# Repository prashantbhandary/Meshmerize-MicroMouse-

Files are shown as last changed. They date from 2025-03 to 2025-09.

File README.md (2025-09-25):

# 🤖 Meshmerize MicroMouse Project





> **A comprehensive autonomous line-following and maze-solving robot project featuring multiple hardware iterations, advanced algorithms, and professional PCB designs.**

## 🏆 Competition Achievements

Our MicroMouse has proven its excellence in prestigious robotics competitions:

- 🥇 **1st Place** - Locus, Pulchowk Campus  
- 🥈 **2nd Place** - Delta 5.0, Dharan IOE  
- 🏅 **5th Place** - Techfest, IIT Bombay 2024

<div align="center">

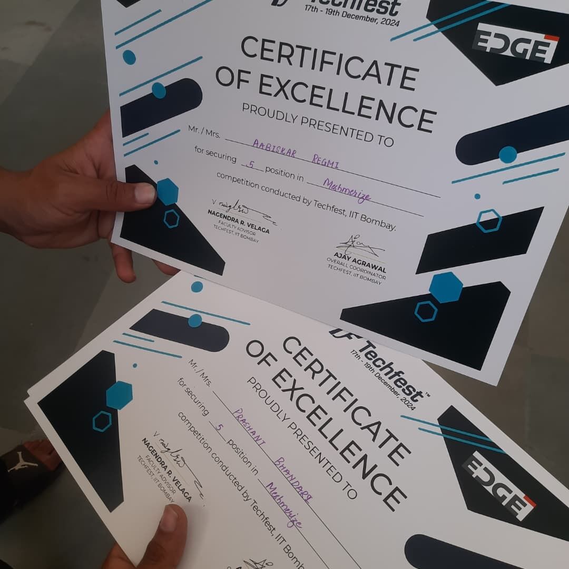
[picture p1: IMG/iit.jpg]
IIT Bombay Certificate

*Certificate of Achievement from IIT Bombay Techfest 2024*

</div>

---

## 📋 Table of Contents

- [🎯 Project Overview](#-project-overview)
- [✨ Key Features](#-key-features)
- [🔧 Hardware Versions](#-hardware-versions)
- [💻 Software Architecture](#-software-architecture)
- [🚀 Getting Started](#-getting-started)
- [📁 Repository Structure](#-repository-structure)
- [🛠️ Installation & Setup](#️-installation--setup)
- [🎮 Usage Instructions](#-usage-instructions)
- [🧠 Algorithms & Control Systems](#-algorithms--control-systems)
- [📷 Project Gallery](#-project-gallery)
- [🤝 Contributing](#-contributing)
- [📄 License](#-license)

---

## 🎯 Project Overview

The **Meshmerize MicroMouse** is an autonomous robot designed to navigate line-following courses and solve complex mazes. This project showcases the evolution of robotics engineering through multiple hardware iterations, from Arduino Nano-based prototypes to advanced ESP32-powered systems.

### What Makes This Project Special?

- **Multiple Hardware Generations**: Evolution from v1.0 to v3.1 with continuous improvements
- **Dual Platform Support**: Both Arduino Nano and ESP32 implementations
- **Professional PCB Design**: Custom-designed circuit boards using KiCad
- **Advanced Algorithms**: LSRB maze-solving with optimized PID control
- **Competition-Tested**: Proven performance in national and international competitions

---

## ✨ Key Features

### 🎯 **Navigation Capabilities**
- **Line Following**: Precise black/white line detection and following
- **Maze Solving**: Autonomous exploration and shortest path execution
- **Multi-Surface Support**: Adaptable to different track conditions

### ⚡ **Performance Optimization**
- **PID Control System**: Smooth and accurate movement control
- **Speed Management**: Adaptive speed control for different track sections
- **Sensor Calibration**: Advanced sensor tuning for reliable detection

### 🔧 **Hardware Excellence**
- **Custom PCB Design**: Professional circuit board layouts
- **Modular Architecture**: Easy maintenance and upgrades
- **Power Management**: Efficient voltage regulation for all components

---

## 🔧 Hardware Versions

<details>
<summary><strong>Arduino Nano Series</strong></summary>

### Version 1.0 - Prototype
- **Microcontroller**: Arduino Nano
- **Motor Driver**: L293D
- **Sensors**: QTR-8A analog sensor array
- **Status**: Initial prototype and testing phase

### Version 2.0 - Enhanced Performance
- **Microcontroller**: Arduino Nano (optimized)
- **Motor Driver**: SparkFun TB6612FNG
- **Sensors**: 8-channel QTR sensor array
- **Improvements**: Better motor control, enhanced PID tuning
- **PCB**: Custom-designed v2.0 PCB

### Version 3.0/3.1 - Professional Grade
- **Microcontroller**: Arduino Nano
- **Features**: Professional PCB design with improved layout
- **Status**: Competition-ready version

</details>

<details>
<summary><strong>ESP32 Series</strong></summary>

### ESP32 Version 1.0
- **Microcontroller**: ESP32 DevKit
- **Development**: PlatformIO-based development
- **Features**: 
  - Wireless capabilities
  - Higher processing power
  - Advanced sensor integration
- **PCB**: Custom ESP32-based PCB design

</details>

---

## 💻 Software Architecture

### Programming Platforms
- **Arduino IDE**: Traditional Arduino Nano development
- **PlatformIO**: Advanced ESP32 development with better library management

### Key Libraries
```cpp
#include <SparkFun_TB6612.h>  // Motor control library
#include <QTRSensors.h>       // Sensor array library
```

### Algorithm Implementation
- **LSRB Algorithm**: Left-Straight-Right-Back priority maze solving
- **PID Control**: Proportional-Integral-Derivative control for smooth movement
- **Path Optimization**: Shortest path calculation and execution

---

## 🚀 Getting Started

### Prerequisites
- Arduino IDE or PlatformIO
- USB cable for programming
- Basic electronics knowledge
- Robotics track or maze for testing

### Quick Setup
1. **Clone the repository**
   ```bash
   git clone https://github.com/prashantbhandary/Meshmerize-MicroMouse-.git
   cd Meshmerize-MicroMouse-
   ```

2. **Choose your platform**
   - For Arduino Nano: Navigate to `ArduinoNano/` folder
   - For ESP32: Navigate to `Esp32/` folder

3. **Select the appropriate version**
   - Pick the version that matches your hardware setup
   - Latest versions recommended for best performance

---

## 📁 Repository Structure

```
📦 Meshmerize-MicroMouse-
├── 🔧 ArduinoNano/
│   ├── 🧪 arduno_nano_v1_TestingCode/
│   │   ├── arduino_sensor_test2.0/
│   │   ├── black_line_maze_2.0/
│   │   ├── motor-testing/
│   │   └── night_nano/
│   ├── 📋 micro_mouse_v1-files/
│   │   ├── codes/ (Line follower, maze solving, testing)
│   │   └── design/ (3D models, PCB files)
│   ├── 🚀 micro_mouse_v2-files/
│   │   ├── BlackLineMazeFinal_v2-Code/
│   │   ├── LineFollowerPid_v2-Code/
│   │   ├── WhiteLineMazeFinal_v2-Code/
│   │   └── micro_mouse_v2-pcb/
│   └── 🏆 micro_mouse_v3_files/
│       ├── micro_mouse_prashant/
│       ├── micro_mouse_v3.0-PCB/
│       └── micro_mouse_v3.1-PCB/
├── 📡 Esp32/
│   ├── LineFolloweEsp32_v1_code/
│   ├── micromouseEsp32_v1_PCB/
│   └── testing_esp32_v1_code/
├── 📸 IMG/
│   ├── Competition videos and images
│   └── Robot demonstration media
└── 📖 README.md
```

---

## 🛠️ Installation & Setup

### For Arduino Nano Versions

1. **Install Required Libraries**
   ```
   - SparkFun TB6612 Motor Driver Library
   - QTRSensors Library
   ```

2. **Hardware Setup**
   - Connect QTR sensors to analog pins A0-A7
   - Wire motor drivers according to pin definitions
   - Connect control switches and LED indicators

3. **Upload Code**
   - Open the desired version in Arduino IDE
   - Select Arduino Nano board
   - Upload the code

### For ESP32 Version

1. **PlatformIO Setup**
   ```bash
   cd Esp32/LineFolloweEsp32_v1_code/Micromouse/
   pio run --target upload
   ```

2. **Hardware Configuration**
   - Follow ESP32 pin definitions in the code
   - Ensure proper power supply (3.3V/5V compatibility)

---

## 🎮 Usage Instructions

### Initial Setup
1. **Calibration Phase**
   - Press switch 1 to start sensor calibration
   - Move the robot over the line during calibration
   - LED indicator confirms successful calibration

2. **Mode Selection**
   - **Switch 2**: Left-hand rule (LHS) priority
   - **Switch 3**: Right-hand rule (RHS) priority

3. **Start Operation**
   - Press switch 1 again to begin line following/maze solving
   - Robot will autonomously navigate the course

### Operating Modes

#### Line Following Mode
- Robot follows black line on white surface (or vice versa)
- PID control ensures smooth tracking
- Adaptive speed control for optimal performance

#### Maze Solving Mode
- **Exploration Phase**: Robot maps the entire maze
- **Optimization Phase**: Calculates shortest path
- **Execution Phase**: Runs the optimized route

---

## 🧠 Algorithms & Control Systems

### LSRB Algorithm (Left-Straight-Right-Back)
```cpp
// Priority decision making
if (left_path_available) {
    turn_left();
} else if (straight_path_available) {
    move_forward();
} else if (right_path_available) {
    turn_right();
} else {
    turn_back(); // Dead end
}
```

### PID Control System
```cpp
// PID calculation for smooth movement
error = sensor_position - desired_position;
derivative = error - lastError;
correction = (kp * error) + (kd * derivative);
motor_speed_adjustment = base_speed ± correction;
```

### Key Parameters
- **Base Speed**: 130-255 (adjustable per version)
- **Kp (Proportional)**: 0.05-0.151 (tuned per hardware)
- **Kd (Derivative)**: 0.1-0.8 (optimized for stability)

---

## 📷 Project Gallery

<div align="center">

### 🤖 Robot Images
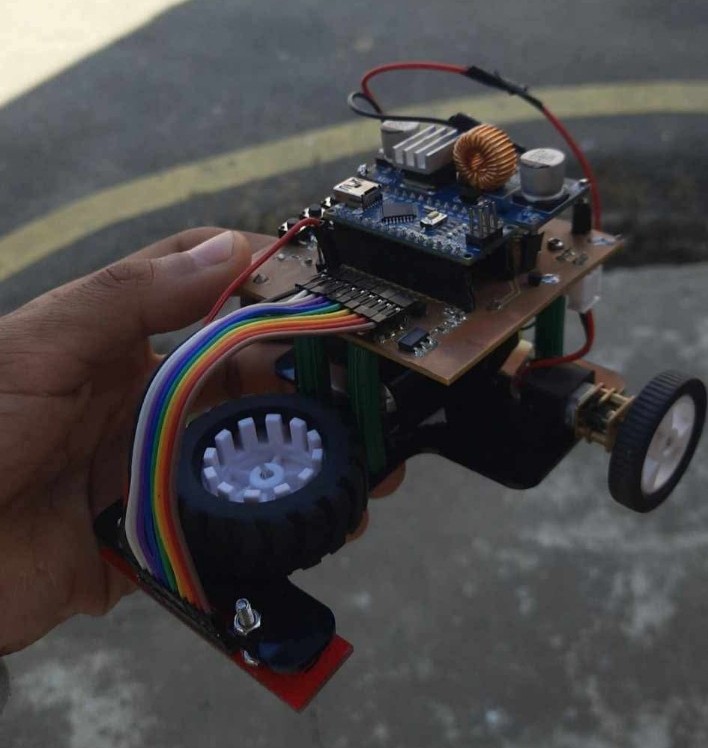
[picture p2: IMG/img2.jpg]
Robot Side View
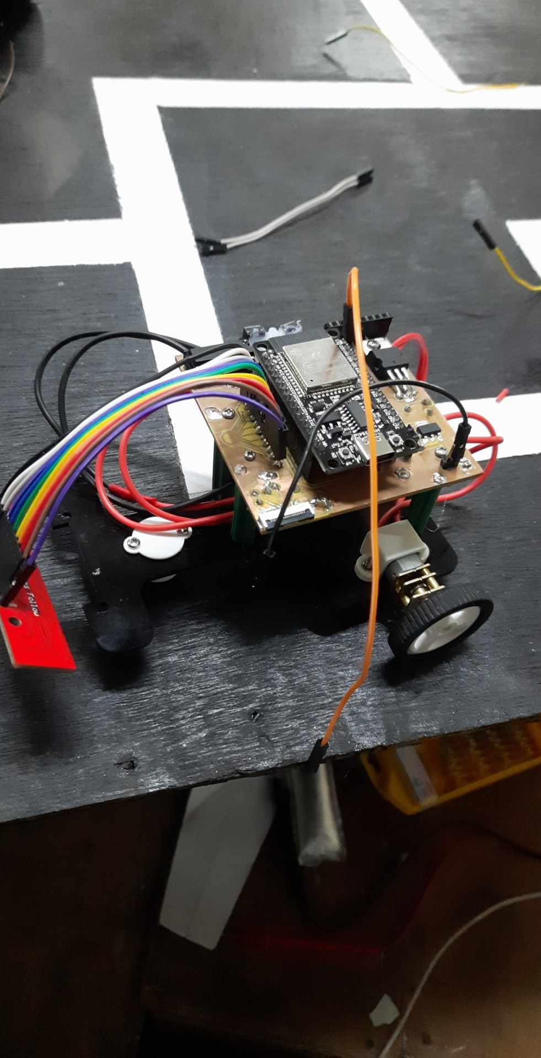
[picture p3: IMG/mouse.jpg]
Robot Front View
 | 
:---: | :---:
*Side Profile* | *Front View*

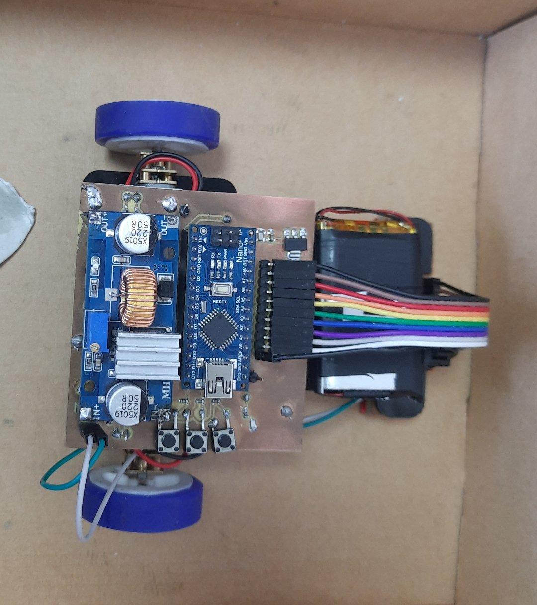
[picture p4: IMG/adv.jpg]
Competition Setup

*Competition Ready Configuration*

### 🎥 Demo Videos
▶️ **[Watch MicroMouse in Action](./IMG/iit_bombay.mp4)**  
*Live demonstration from IIT Bombay competition*

▶️ **[Advanced Maze Solving Demo](./IMG/469240304_8275277389243894_8094127931744390612_n.mp4)**  
*Complex maze navigation showcase*

</div>

---

## 🤝 Contributing

We welcome contributions to improve the MicroMouse project! Here's how you can help:

### Ways to Contribute
- 🐛 **Bug Reports**: Found an issue? Let us know!
- 💡 **Feature Requests**: Suggest new capabilities
- 🔧 **Code Improvements**: Optimize algorithms or add new features
- 📚 **Documentation**: Help improve guides and tutorials
- 🔬 **Testing**: Try different hardware configurations

### Development Setup
1. Fork the repository
2. Create a feature branch (`git checkout -b feature/AmazingFeature`)
3. Make your changes
4. Test thoroughly with hardware
5. Commit your changes (`git commit -m 'Add AmazingFeature'`)
6. Push to the branch (`git push origin feature/AmazingFeature`)
7. Open a Pull Request

---

## 📞 Contact & Support

- **Project Maintainer**: Prashant Bhandary
- **GitHub**: [@prashantbhandary](https://github.com/prashantbhandary)
- **Repository**: [Meshmerize-MicroMouse-](https://github.com/prashantbhandary/Meshmerize-MicroMouse-)
- **Portfolio Website**: 🌐 [bhandari-prashant.com.np](https://bhandari-prashant.com.np)

### Getting Help
- 📋 **Issues**: Use GitHub Issues for bug reports
- 💬 **Discussions**: Join repository discussions for general questions
- 📖 **Wiki**: Check the wiki for detailed guides (coming soon)

---

## 📄 License

This project is licensed under the MIT License - see the [LICENSE](LICENSE) file for details.

### What this means:
- ✅ Use in personal and commercial projects
- ✅ Modify and distribute freely
- ✅ Include in other projects
- 📋 Attribution required

---

<div align="center">

### 🌟 Star this project if you found it helpful!

**Made with ❤️ by the Robotics Team, WRC**

*"Engineering the future, one algorithm at a time."*




</div>
  
### Achievements:
1. Winner at **Locus 2025**, Pulchowk IOE.
2. 1st Runner-up at **Delta 5.0 ERC**, Dharan IOE.
3. Top 5 finish at **Techfest, IIT Bombay 2024** amidst tough competition.

This project was a huge learning experience, teaching us valuable lessons in algorithm optimization, hardware design, and problem-solving.

## Special Thanks:

- **Teammates and Mentors**: Aabiskar Regmi, Sanjog Sapkota, Siddartha Gupta

Can’t wait to tackle even bigger challenges next! 🚀

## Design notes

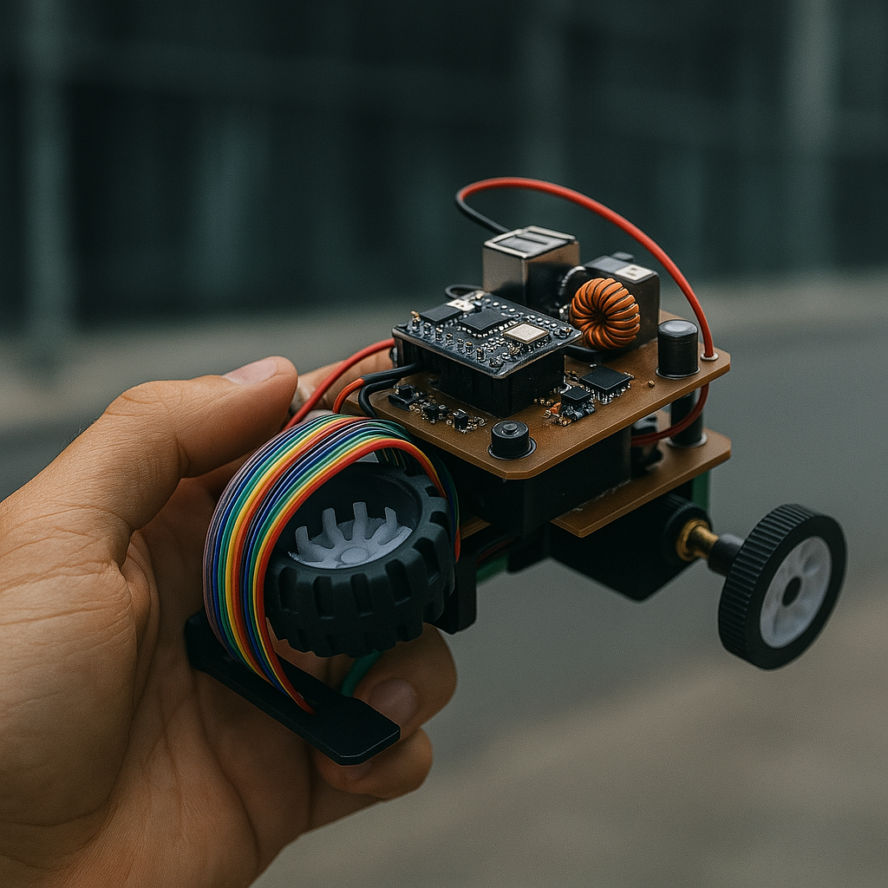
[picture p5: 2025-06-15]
IMG/chatgpt.png

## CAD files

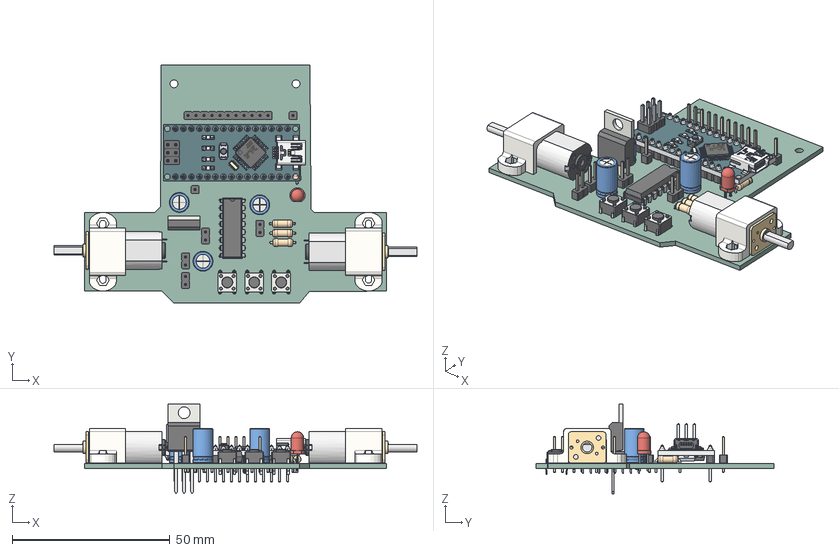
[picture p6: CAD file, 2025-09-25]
ArduinoNano/micro_mouse_v3_files/micro_mouse_prashant/micro_mouse_prashant/micro_mouse_prashant.step
115.1 x 75.5 x 28.5 mm
PinHeader_1x11_P2.54mm_Vertical
DIP-16_W7.62mm
PinHeader_1x02_P2.54mm_Vertical x 4
SW_PUSH_6mm x 3
nano-board
2pin_header__02 x 3
15pin_header__ x 2
atmega328
ftdi FT232rl
smt_resistor222 x 5
led x 4
16mhz crystal - measured
MINIUSBSHELL
MINIUSBCORE
MINI USB CONTACT x 5
cap106C x 2
reset core
reset shell
nano - reg
NANO DIODE
189 RESISTOR PACK
102 RESISTOR PACK
C_Radial_D6.3mm_H11.0mm_P2.50mm x 2
R_Axial_DIN0207_L6.3mm_D2.5mm_P7.62mm_Horizontal x 4
Bracket x 2
C_Radial_D6.3mm_H7.0mm_P2.50mm
LED_D4.0mm
Gear Box x 2
Shaft x 2
Motor x 2
PinHeader_1x01_P2.54mm_Vertical x 2
TO-220-3_Vertical
micro_mouse_prashant_PCB

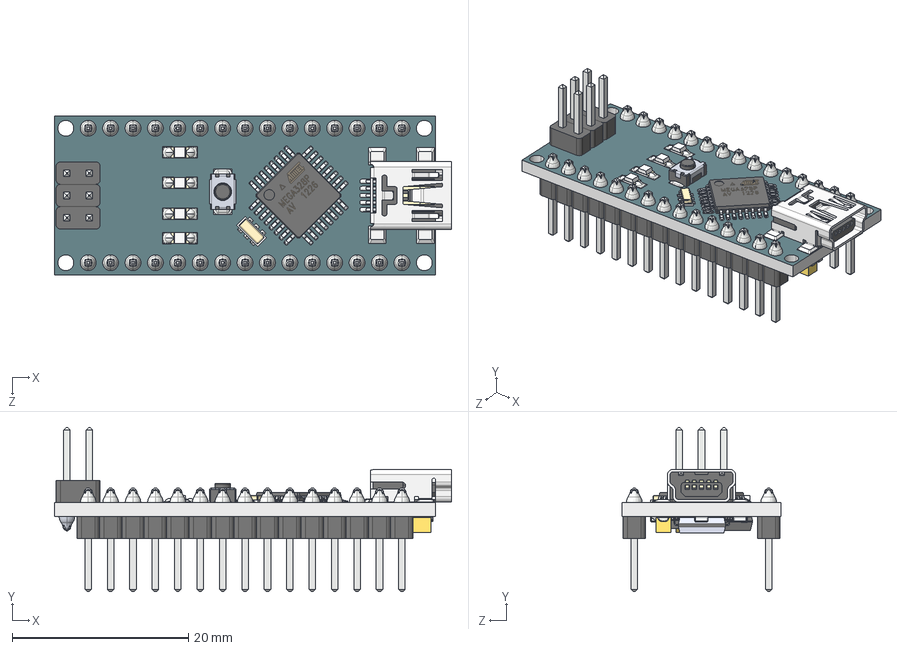
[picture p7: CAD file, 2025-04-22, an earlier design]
ArduinoNano/micro_mouse_v1-files/design/3D/arduino nano.STEP
45.0 x 18.6 x 18.0 mm
nano-board
2pin_header__02 x 3
15pin_header__ x 2
atmega328
ftdi FT232rl
smt_resistor222 x 5
led x 4
16mhz crystal - measured
MINIUSBSHELL
MINIUSBCORE
MINI USB CONTACT x 5
cap106C x 2
reset core
reset shell
nano - reg
NANO DIODE
189 RESISTOR PACK
102 RESISTOR PACK

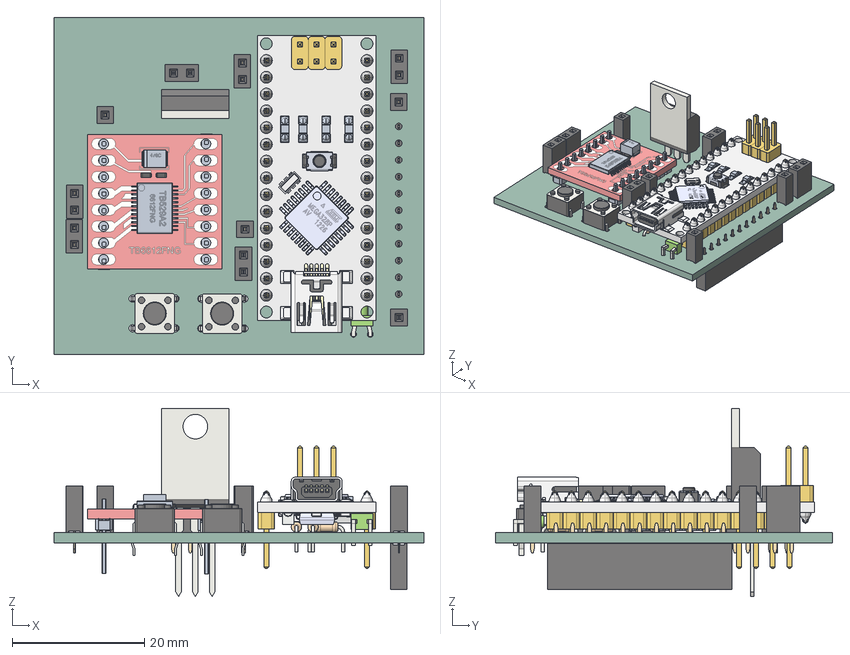
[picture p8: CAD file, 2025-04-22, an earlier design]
ArduinoNano/micro_mouse_v1-files/design/Ckt_PCB_files/Micro_mouse1.step
56.1 x 51.1 x 28.5 mm
arduino nano
SW_PUSH_6mm x 2
R_Axial_DIN0204_L36mm_D16mm_P508mm_Horizontal x 3
PinSocket_1x01_P254mm_Vertical x 4
LED_D1.8mm_W1.8mm_H2.4mm_Horizontal_O1.27mm_Z1.6mm
PinSocket_1x02_P254mm_Vertical x 6
TO-220-3_Vertical
DOBLE PUENTE H v36
PinSocket_1x11_P254mm_Vertical
Micro_mouse1_PCB

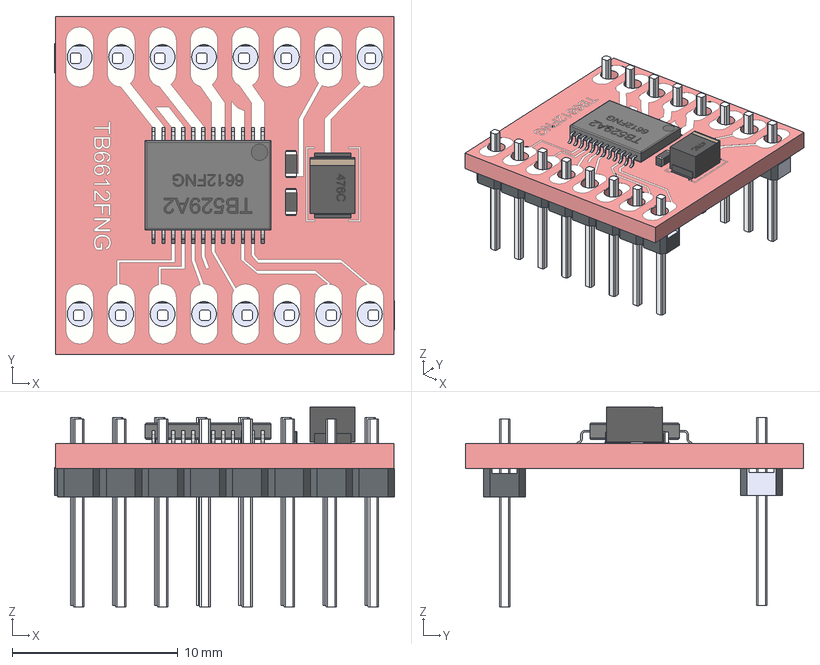
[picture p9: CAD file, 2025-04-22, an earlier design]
ArduinoNano/micro_mouse_v1-files/design/3D/DOBLE PUENTE H.step
20.5 x 20.4 x 12.1 mm
TB6612FNG
capacitor
capacitor_v1 x 2
header_8 x 2

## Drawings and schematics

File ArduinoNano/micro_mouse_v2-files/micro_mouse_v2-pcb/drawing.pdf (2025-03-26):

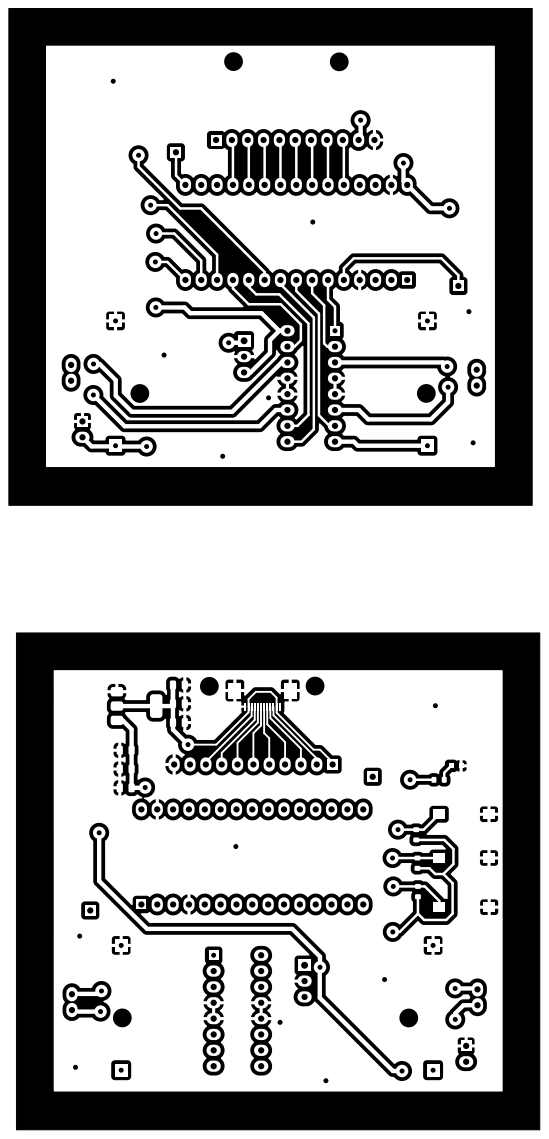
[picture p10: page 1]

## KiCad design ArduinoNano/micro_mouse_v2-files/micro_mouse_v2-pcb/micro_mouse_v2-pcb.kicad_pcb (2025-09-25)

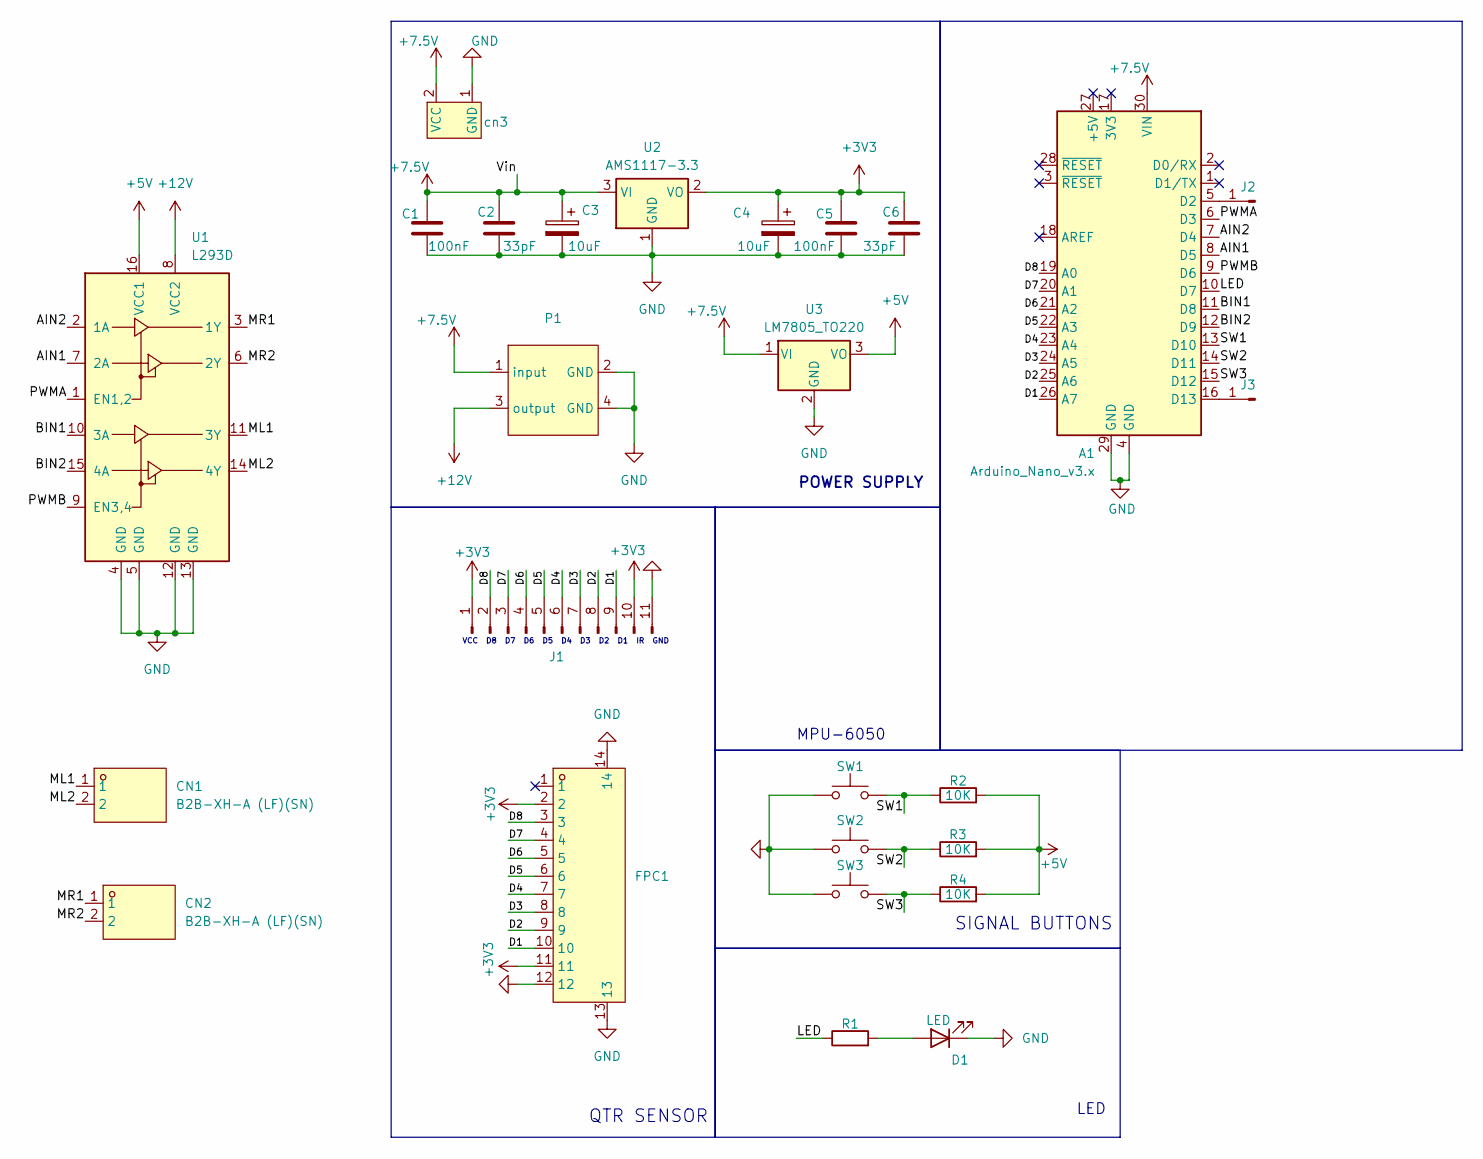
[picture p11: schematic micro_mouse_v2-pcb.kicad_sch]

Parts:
A1: Arduino_Nano_v3.x; Arduino_Nano
C1, C5: 100nF; C_0805_2012Metric; lcsc C100072
C2, C6: 33pF; C_0805_2012Metric; lcsc C100072
C3, C4: 10uF; C_0805_2012Metric; lcsc C119052
CN1, CN2: B2B-XH-A (LF)(SN); CONN-TH_B2B-XH-A-LF-SN; LCSC Part C158012
D1: LED; LED0603-RD
FPC1: FPC-05F-12PH20; FPC-SMD_12P-P0.50_FPC-05F-12PH20; LCSC Part C2856799
J1: Conn_01x11_Pin; PinHeader_1x11_P2.54mm_Vertical
J2, J3: Conn_01x01_Pin; PinHeader_1x01_P2.54mm_Vertical
P1: buck_boost converter
R1: R; R_0603_1608Metric
R2, R3, R4: 10K; R_0603_1608Metric
SW1, SW2, SW3: SW_Push; SW-SMD_L6.0-W3.3-LS8.0
U1: L293D; DIP-16_W7.62mm
U2: AMS1117-3.3; SOT-223-3_TabPin2
U3: LM7805_TO220; TO-220-3_Vertical
cn3: PinSocket_1x02_P2.54mm_Vertical

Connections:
+3V3: C4.1, C5.1, C6.1, FPC1.2, FPC1.11, J1.1, J1.10, U2.2 (VO)
+5V: R2.2, R3.2, R4.2, U1.16 (VCC1), U3.3 (VO)
+7.5V: A1.30 (VIN), C1.1, C2.1, C3.1, P1.1 (input), U2.3 (VI), U3.1 (VI), cn3.2 (VCC)
+12V: P1.3 (output), U1.8 (VCC2)
/AIN1: A1.8 (D5), U1.7 (2A)
/AIN2: A1.7 (D4), U1.2 (1A)
/BIN1: A1.11 (D8), U1.10 (3A)
/BIN2: A1.12 (D9), U1.15 (4A)
/D1: A1.26 (A7), FPC1.10, J1.9
/D2: A1.25 (A6), FPC1.9, J1.8
/D3: A1.24 (A5), FPC1.8, J1.7
/D4: A1.23 (A4), FPC1.7, J1.6
/D5: A1.22 (A3), FPC1.6, J1.5
/D6: A1.21 (A2), FPC1.5, J1.4
/D7: A1.20 (A1), FPC1.4, J1.3
/D8: A1.19 (A0), FPC1.3, J1.2
/LED: A1.10 (D7), R1.1
/ML1: CN1.1, U1.11 (3Y)
/ML2: CN1.2, U1.14 (4Y)
/MR1: CN2.1, U1.3 (1Y)
/MR2: CN2.2, U1.6 (2Y)
/PWMA: A1.6 (D3), U1.1 (EN1,2)
/PWMB: A1.9 (D6), U1.9 (EN3,4)
/SW1: A1.13 (D10), R2.1, SW1.2
/SW2: A1.14 (D11), R3.1, SW2.2
/SW3: A1.15 (D12), R4.1, SW3.2
GND: A1.4 (GND), A1.29 (GND), C1.2, C2.2, C3.2, C4.2, C5.2, C6.2, D1.1 (K), FPC1.12, FPC1.13, FPC1.14, J1.11, P1.2 (GND), P1.4 (GND), SW1.1, SW2.1, SW3.1, U1.4 (GND), U1.5 (GND), U1.12 (GND), U1.13 (GND), U2.1 (GND), U3.2 (GND), cn3.1 (GND)
unnamed: A1.5 (D2), J2.1
unnamed: A1.16 (D13), J3.1
unnamed: D1.2 (A), R1.2

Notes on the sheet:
QTR SENSOR
LED
SIGNAL BUTTONS
POWER SUPPLY
VCC D8 D7 D6 D5 D4 D3 D2 D1 IR GND
MPU-6050

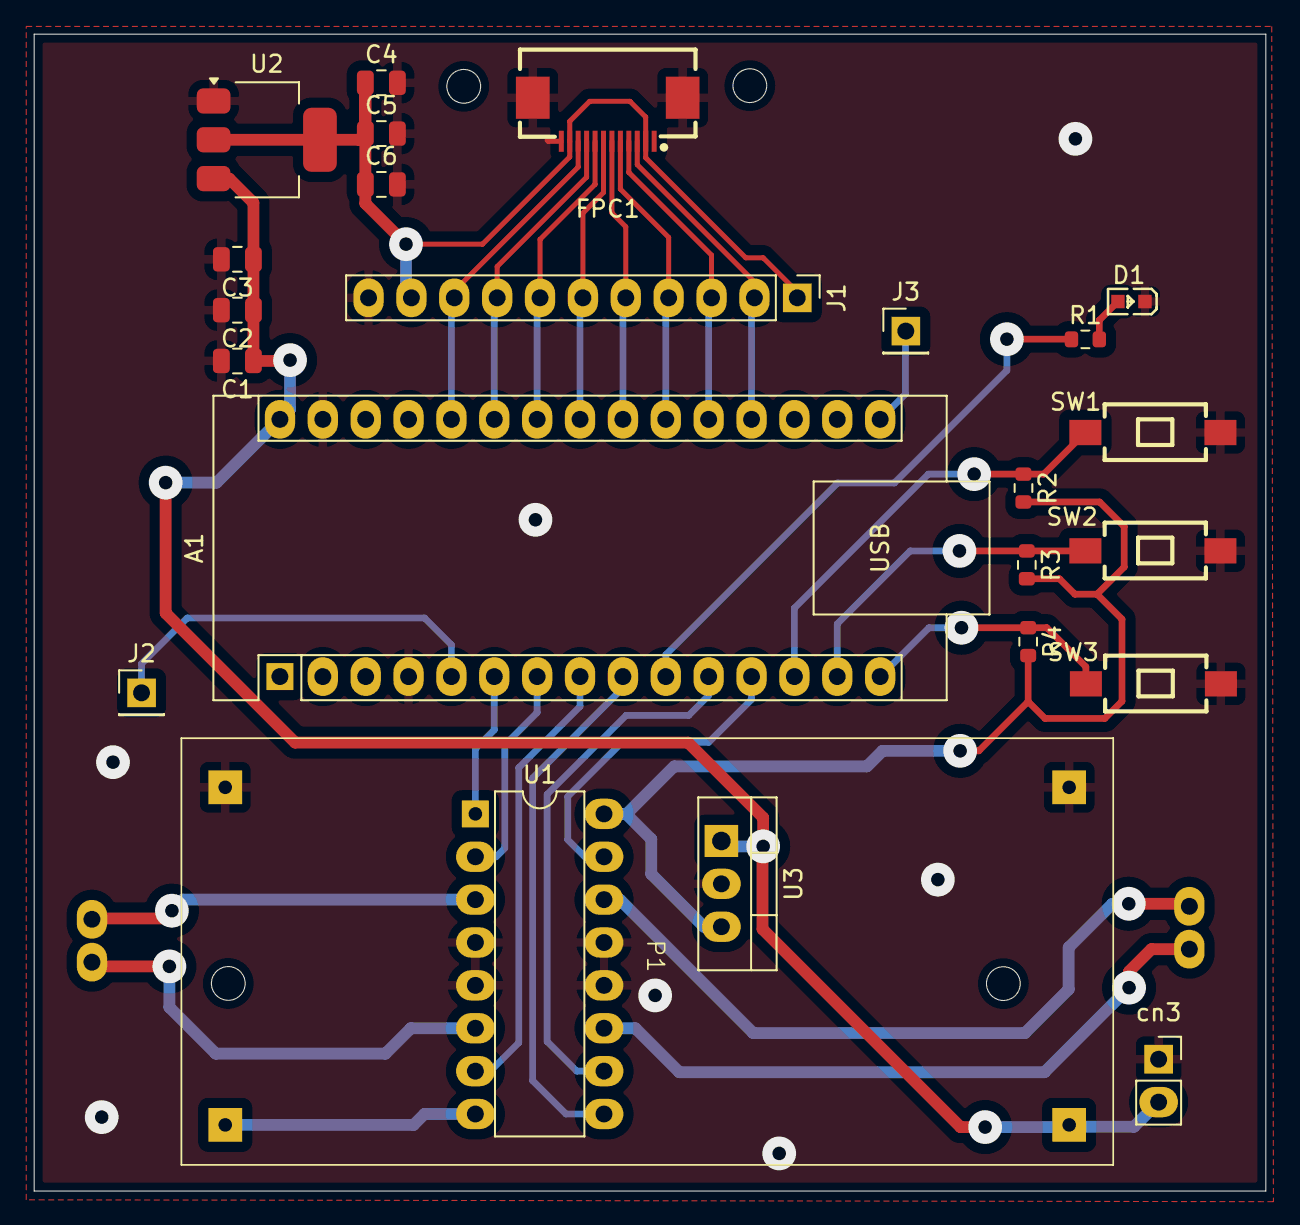
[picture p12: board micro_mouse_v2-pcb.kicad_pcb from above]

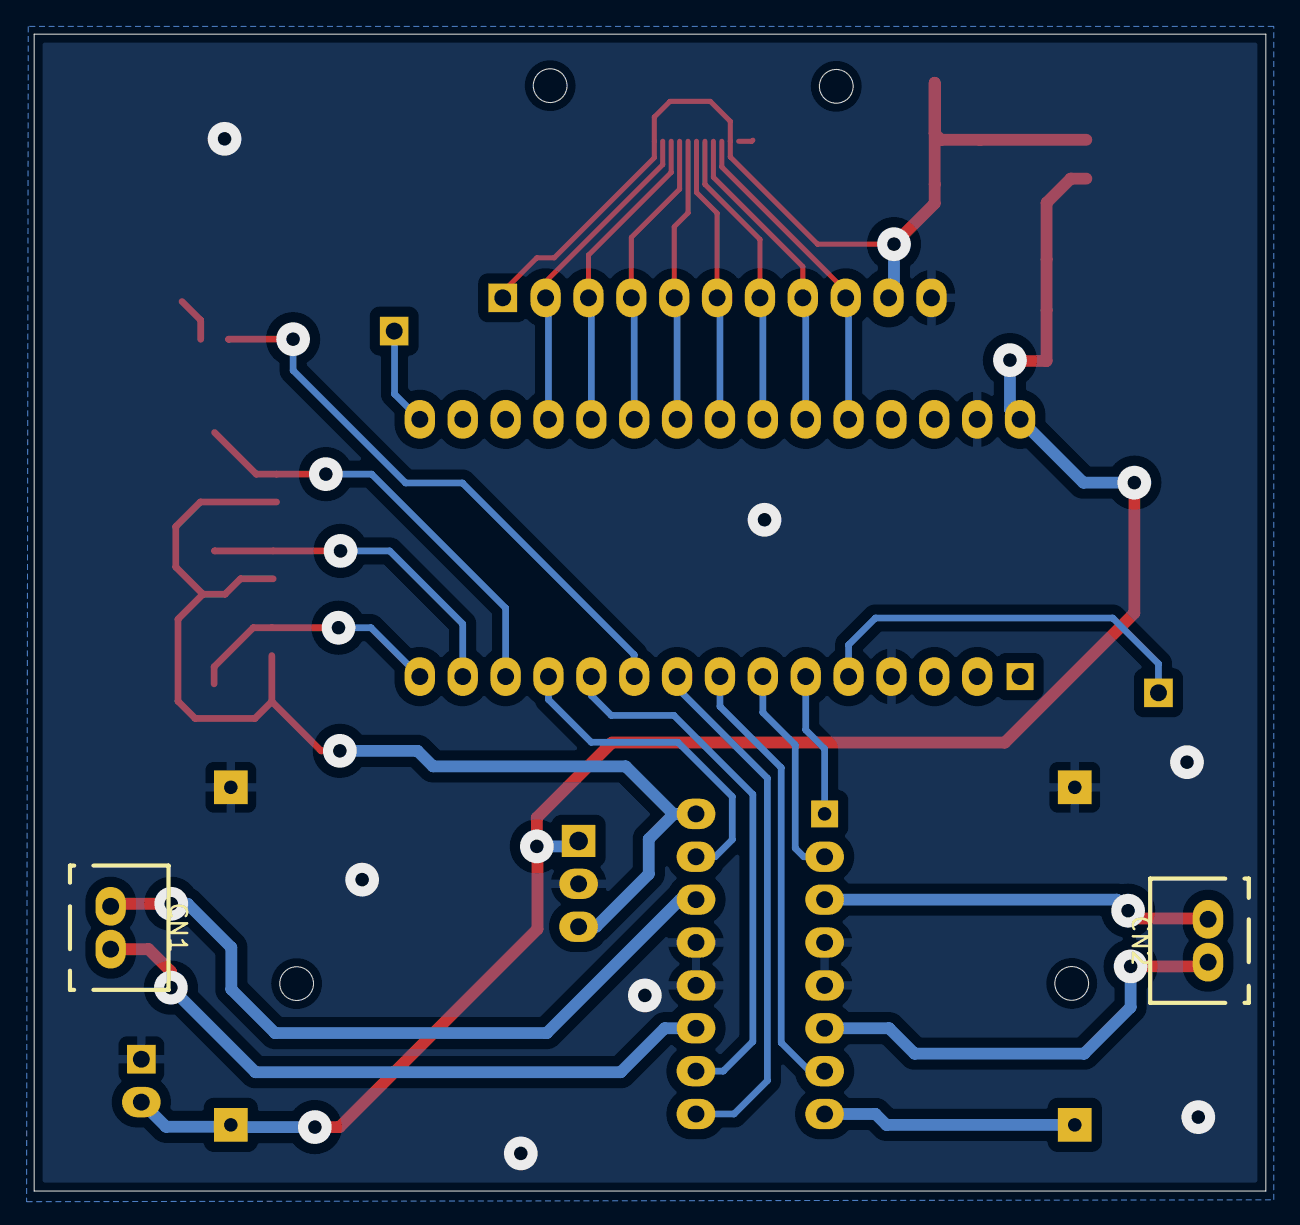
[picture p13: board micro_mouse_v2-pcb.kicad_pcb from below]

Board: 2 copper layers, 73.0 x 68.5 mm, 26 parts (2 on the bottom side), 30 nets.

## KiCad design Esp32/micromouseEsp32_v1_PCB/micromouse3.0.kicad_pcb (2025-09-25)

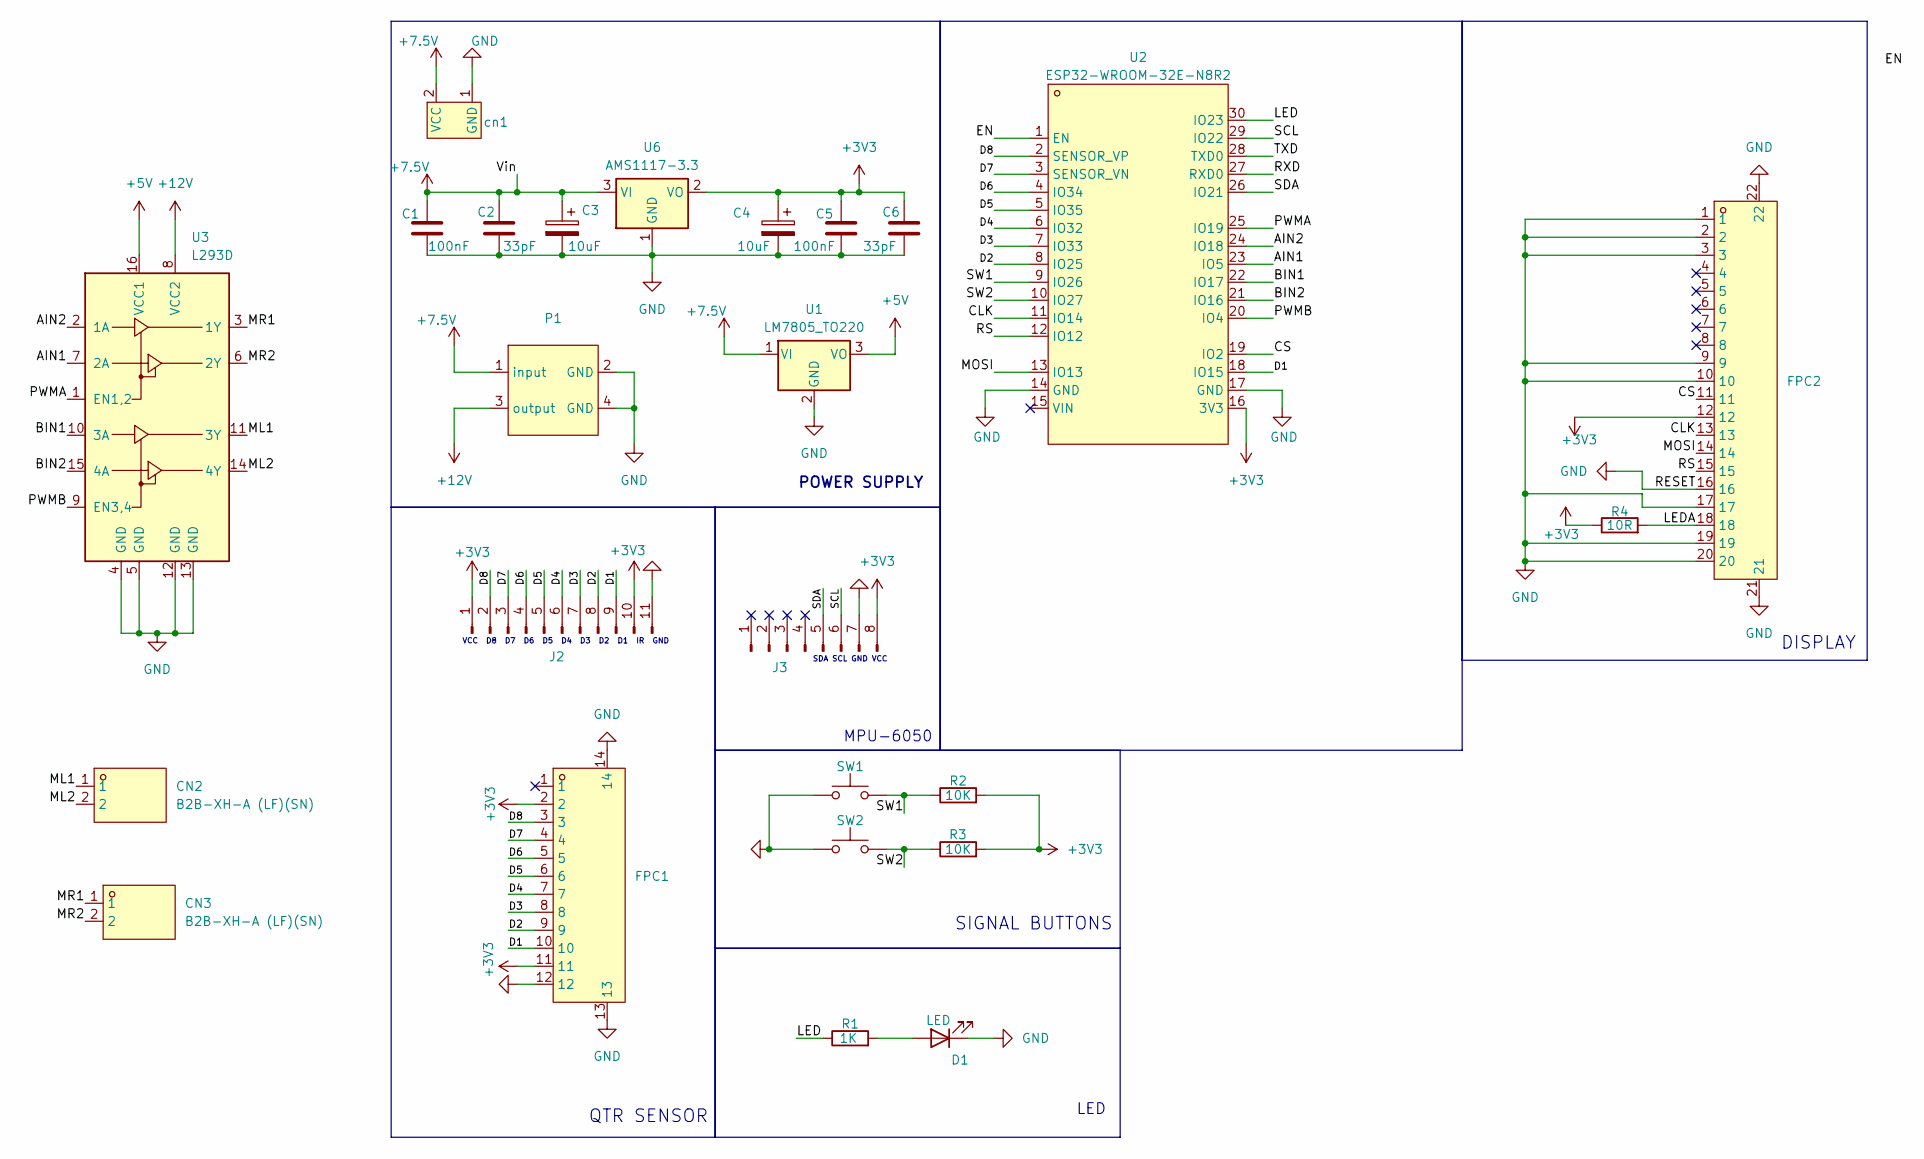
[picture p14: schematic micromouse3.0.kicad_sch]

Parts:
C1, C5: 100nF; C_0805_2012Metric; lcsc C100072
C2, C6: 33pF; C_0805_2012Metric; lcsc C100072
C3, C4: 10uF; C_0805_2012Metric; lcsc C119052
CN2, CN3: B2B-XH-A (LF)(SN); CONN-TH_B2B-XH-A-LF-SN; LCSC Part C158012
D1: LED; LED0603-RD
FPC1: FPC-05F-12PH20; FPC-SMD_12P-P0.50_FPC-05F-12PH20; LCSC Part C2856799
FPC2: FPC-05F-20PH20; FPC-SMD_20P-P0.50_XUNPU_FPC-05F-20PH20; LCSC Part C2856803
J2: Conn_01x11_Pin; PinHeader_1x11_P2.54mm_Vertical
J3: Conn_01x08_Pin; PinHeader_1x08_P2.54mm_Vertical
P1: buck_boost converter
R1: 1K; R_0603_1608Metric
R2, R3: 10K; R_0603_1608Metric
R4: 10R; R_0603_1608Metric
SW1, SW2: SW_Push; SW-SMD_L6.0-W3.3-LS8.0
U1: LM7805_TO220; TO-220-3_Vertical
U2: ESP32-WROOM-32E-N8R2; esp32 dev board; LCSC Part C5361945
U3: L293D; DIP-16_W7.62mm
U6: AMS1117-3.3; SOT-223-3_TabPin2
cn1: PinSocket_1x02_P2.54mm_Vertical

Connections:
+3V3: C4.1, C5.1, C6.1, FPC1.2, FPC1.11, FPC2.12, J2.1, J2.10, J3.8, R2.2, R3.2, R4.1, U2.16 (3V3), U6.2 (VO)
+5V: U1.3 (VO), U3.16 (VCC1)
+7.5V: C1.1, C2.1, C3.1, P1.1 (input), U1.1 (VI), U6.3 (VI), cn1.2 (VCC)
+12V: P1.3 (output), U3.8 (VCC2)
/AIN1: U2.23 (IO5), U3.7 (2A)
/AIN2: U2.24 (IO18), U3.2 (1A)
/BIN1: U2.22 (IO17), U3.10 (3A)
/BIN2: U2.21 (IO16), U3.15 (4A)
/CLK: FPC2.13, U2.11 (IO14)
/CS: FPC2.11, U2.19 (IO2)
/D1: FPC1.10, J2.9, U2.18 (IO15)
/D2: FPC1.9, J2.8, U2.8 (IO25)
/D3: FPC1.8, J2.7, U2.7 (IO33)
/D4: FPC1.7, J2.6, U2.6 (IO32)
/D5: FPC1.6, J2.5, U2.5 (IO35)
/D6: FPC1.5, J2.4, U2.4 (IO34)
/D7: FPC1.4, J2.3, U2.3 (SENSOR_VN)
/D8: FPC1.3, J2.2, U2.2 (SENSOR_VP)
/EN: U2.1 (EN)
/LED: R1.1, U2.30 (IO23)
/LEDA: FPC2.18, R4.2
/ML1: CN2.1, U3.11 (3Y)
/ML2: CN2.2, U3.14 (4Y)
/MOSI: FPC2.14, U2.13 (IO13)
/MR1: CN3.1, U3.3 (1Y)
/MR2: CN3.2, U3.6 (2Y)
/PWMA: U2.25 (IO19), U3.1 (EN1,2)
/PWMB: U2.20 (IO4), U3.9 (EN3,4)
/RS: FPC2.15, U2.12 (IO12)
/RXD: U2.27 (RXD0)
/SCL: J3.6, U2.29 (IO22)
/SDA: J3.5, U2.26 (IO21)
/SW1: R2.1, SW1.2, U2.9 (IO26)
/SW2: R3.1, SW2.2, U2.10 (IO27)
/TXD: U2.28 (TXD0)
GND: C1.2, C2.2, C3.2, C4.2, C5.2, C6.2, D1.1 (K), FPC1.12, FPC1.13, FPC1.14, FPC2.1, FPC2.2, FPC2.3, FPC2.9, FPC2.10, FPC2.16, FPC2.17, FPC2.19, FPC2.20, FPC2.21, FPC2.22, J2.11, J3.7, P1.2 (GND), P1.4 (GND), SW1.1, SW2.1, U1.2 (GND), U2.14 (GND), U2.17 (GND), U3.4 (GND), U3.5 (GND), U3.12 (GND), U3.13 (GND), U6.1 (GND), cn1.1 (GND)
unnamed: D1.2 (A), R1.2

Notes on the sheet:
SDA SCL GND VCC
SIGNAL BUTTONS
MPU-6050
DISPLAY
POWER SUPPLY
QTR SENSOR
LED
VCC D8 D7 D6 D5 D4 D3 D2 D1 IR GND

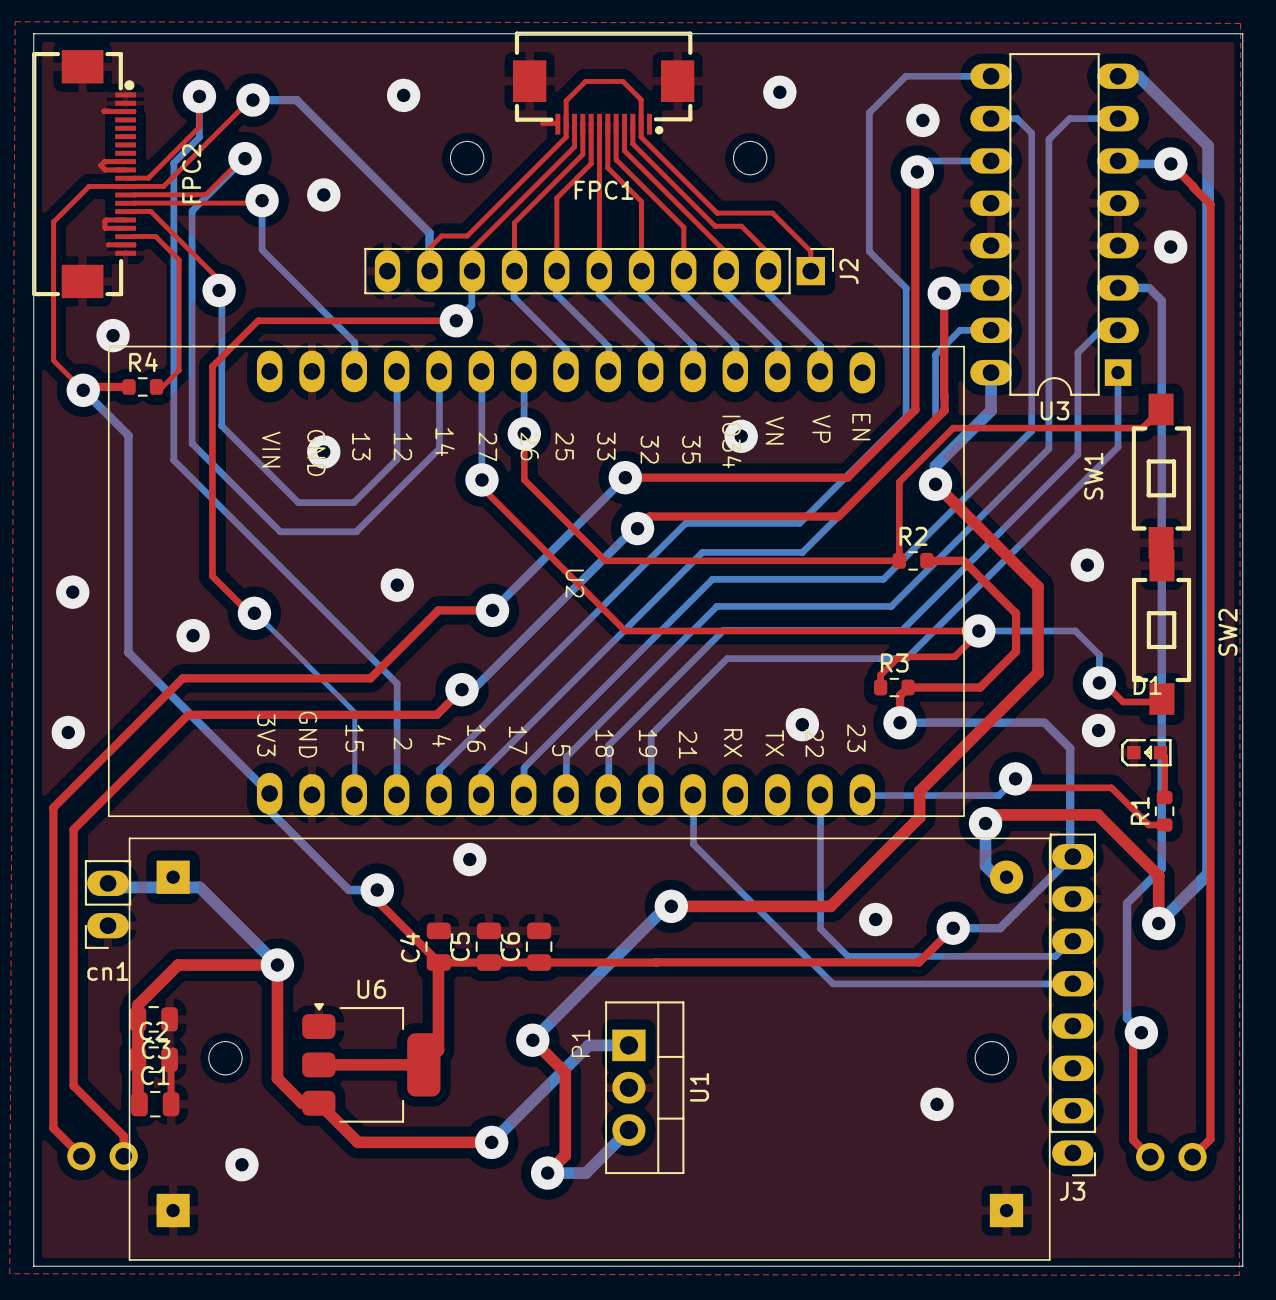
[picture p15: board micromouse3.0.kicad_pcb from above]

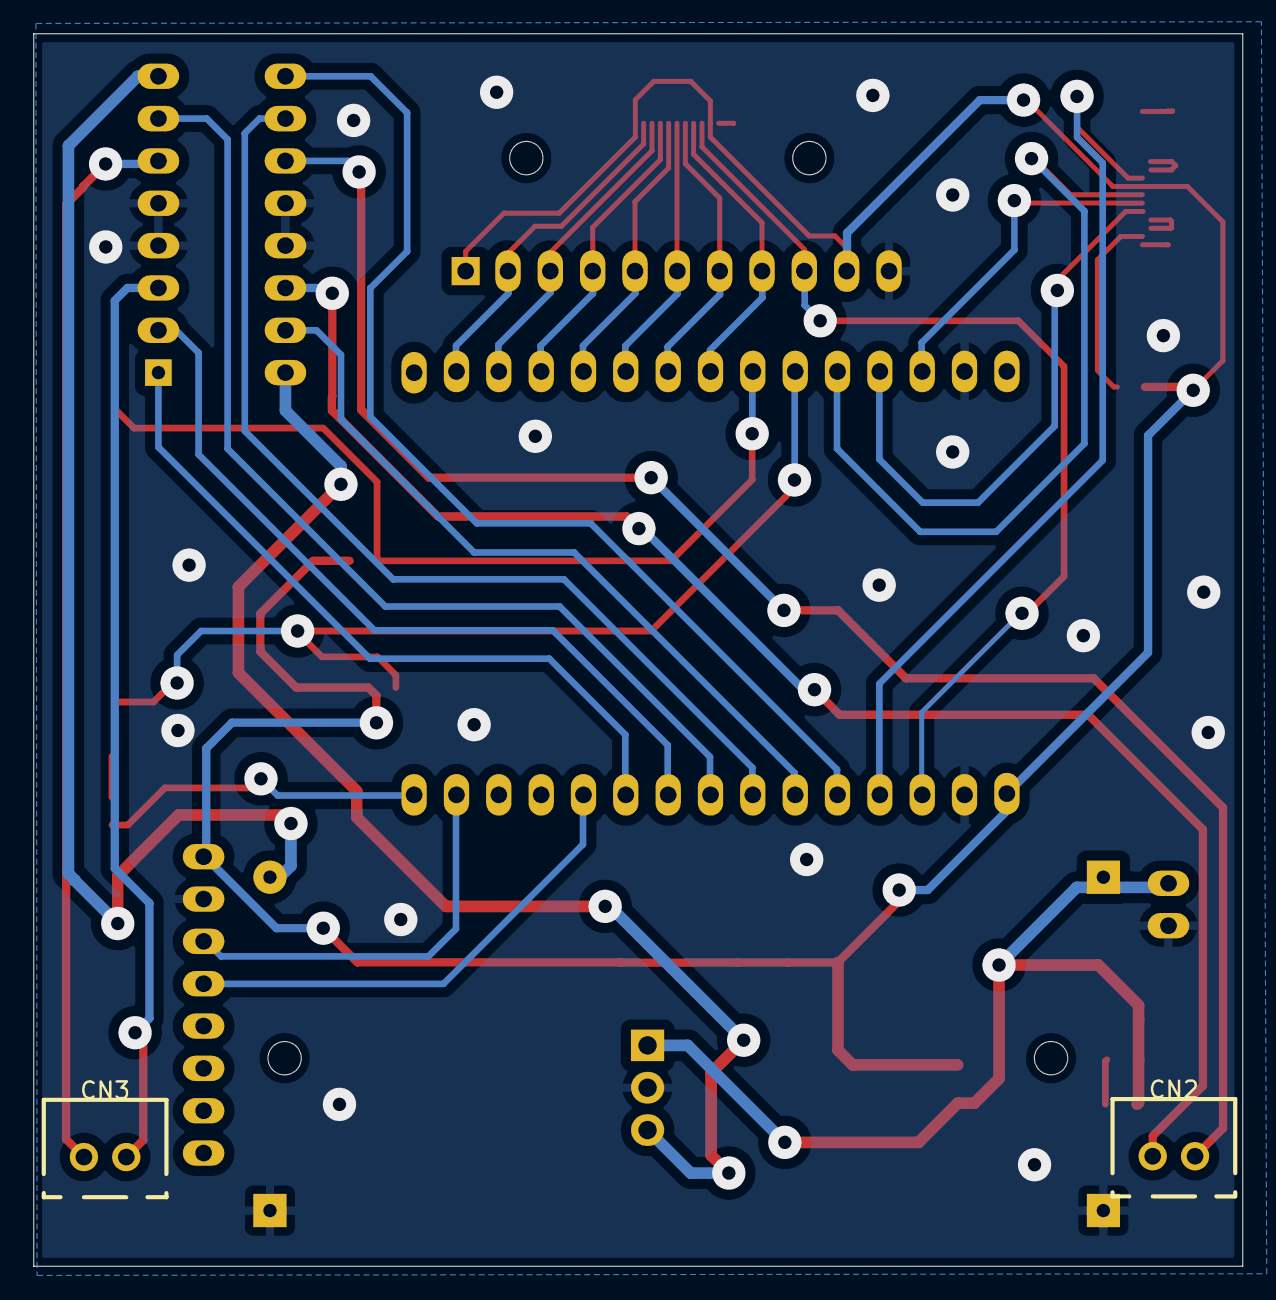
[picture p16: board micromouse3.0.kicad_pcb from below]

Board: 2 copper layers, 72.5 x 73.9 mm, 25 parts (2 on the bottom side), 34 nets.

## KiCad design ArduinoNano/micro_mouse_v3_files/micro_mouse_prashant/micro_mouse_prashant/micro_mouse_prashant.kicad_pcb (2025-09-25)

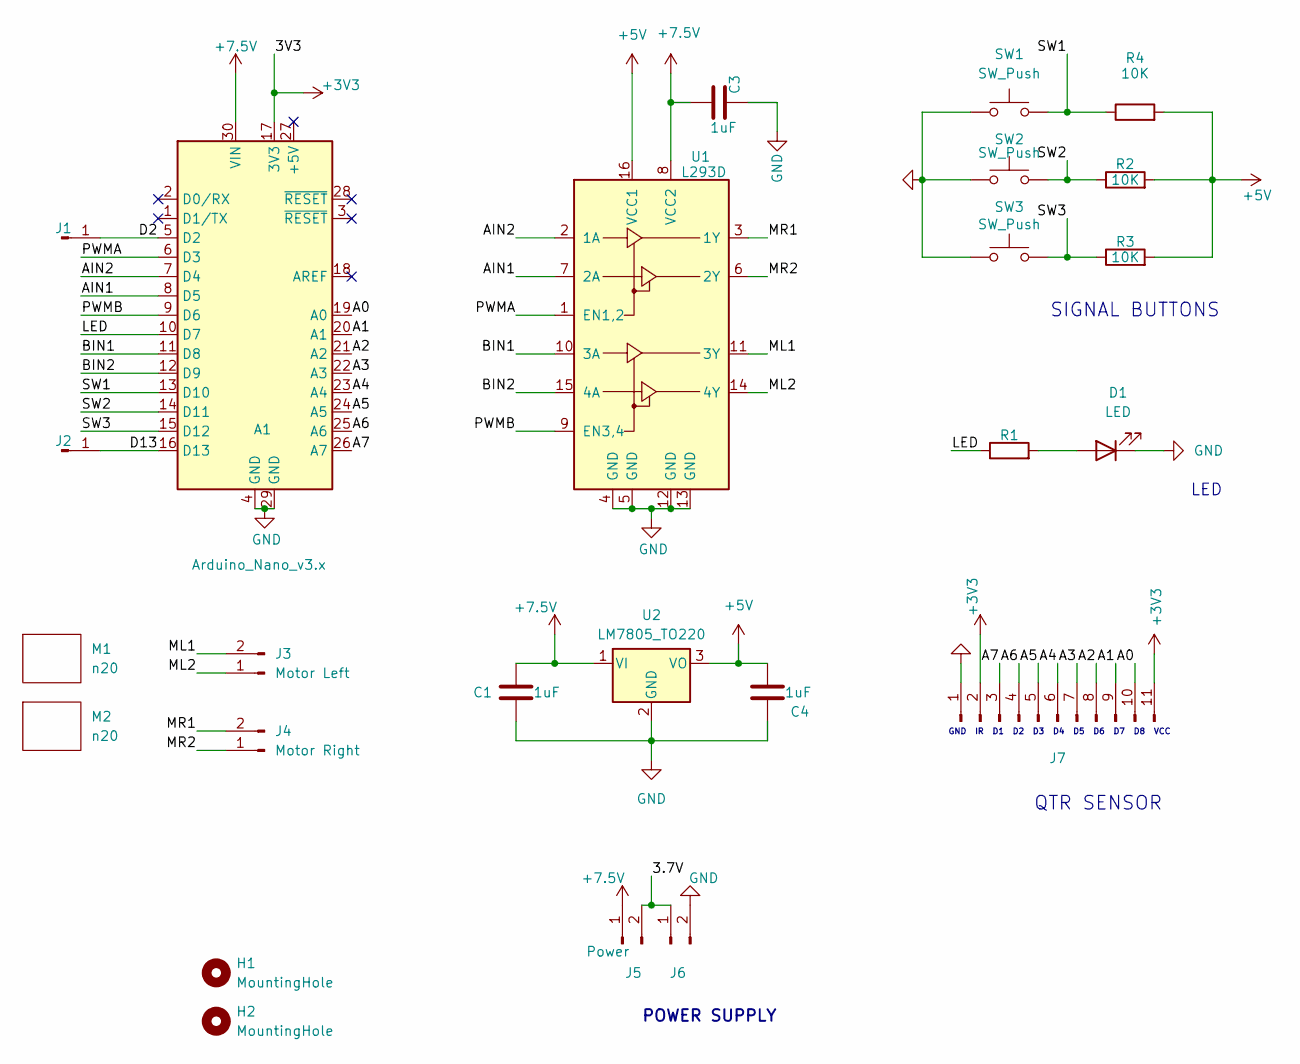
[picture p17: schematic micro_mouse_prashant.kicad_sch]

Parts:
A1: Arduino_Nano_v3.x; Arduino_Nano
C1: 1uF; C_Radial_D6.3mm_H7.0mm_P2.50mm; lcsc C100072
C3, C4: 1uF; C_Radial_D6.3mm_H11.0mm_P2.50mm; lcsc C100072
D1: LED; LED_D4.0mm
H1, H2: MountingHole; MountingHole_2.5mm
J1, J2: Conn_01x01_Pin; PinHeader_1x01_P2.54mm_Vertical
J3: Motor Left; PinHeader_1x02_P2.54mm_Vertical
J4: Motor Right; PinHeader_1x02_P2.54mm_Vertical
J5, J6: Power; PinHeader_1x02_P2.54mm_Vertical
J7: Conn_01x11_Pin; PinHeader_1x11_P2.54mm_Vertical
M1, M2: n20; N20 Gear Motor
R1: R; R_Axial_DIN0207_L6.3mm_D2.5mm_P7.62mm_Horizontal
R2, R3, R4: 10K; R_Axial_DIN0207_L6.3mm_D2.5mm_P7.62mm_Horizontal
SW1, SW2, SW3: SW_Push; SW_PUSH_6mm
U1: L293D; DIP-16_W7.62mm
U2: LM7805_TO220; TO-220-3_Vertical

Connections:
+3V3: A1.17 (3V3), J7.2, J7.11
+5V: C4.1, R2.2, R3.2, R4.2, U1.16 (VCC1), U2.3 (VO)
+7.5V: A1.30 (VIN), C1.1, C3.2, J5.1, U1.8 (VCC2), U2.1 (VI)
/3.7V: J5.2, J6.1
/A0: A1.19 (A0), J7.10
/A1: A1.20 (A1), J7.9
/A2: A1.21 (A2), J7.8
/A3: A1.22 (A3), J7.7
/A4: A1.23 (A4), J7.6
/A5: A1.24 (A5), J7.5
/A6: A1.25 (A6), J7.4
/A7: A1.26 (A7), J7.3
/AIN1: A1.8 (D5), U1.7 (2A)
/AIN2: A1.7 (D4), U1.2 (1A)
/BIN1: A1.11 (D8), U1.10 (3A)
/BIN2: A1.12 (D9), U1.15 (4A)
/D2: A1.5 (D2), J1.1
/D13: A1.16 (D13), J2.1
/LED: A1.10 (D7), R1.1
/ML1: J3.2, U1.11 (3Y)
/ML2: J3.1, U1.14 (4Y)
/MR1: J4.2, U1.3 (1Y); also elsewhere on the board
/MR2: J4.1, U1.6 (2Y); also elsewhere on the board
/PWMA: A1.6 (D3), U1.1 (EN1,2)
/PWMB: A1.9 (D6), U1.9 (EN3,4)
/SW1: A1.13 (D10), R4.1, SW1.2
/SW2: A1.14 (D11), R2.1, SW2.2
/SW3: A1.15 (D12), R3.1, SW3.2
GND: A1.4 (GND), A1.29 (GND), C1.2, C3.1, C4.2, D1.1 (K), J6.2, J7.1, SW1.1, SW2.1, SW3.1, U1.4 (GND), U1.5 (GND), U1.12 (GND), U1.13 (GND), U2.2 (GND)
unnamed: D1.2 (A), R1.2

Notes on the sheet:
LED
SIGNAL BUTTONS
QTR SENSOR
POWER SUPPLY
GND IR D1 D2 D3 D4 D5 D6 D7 D8 VCC

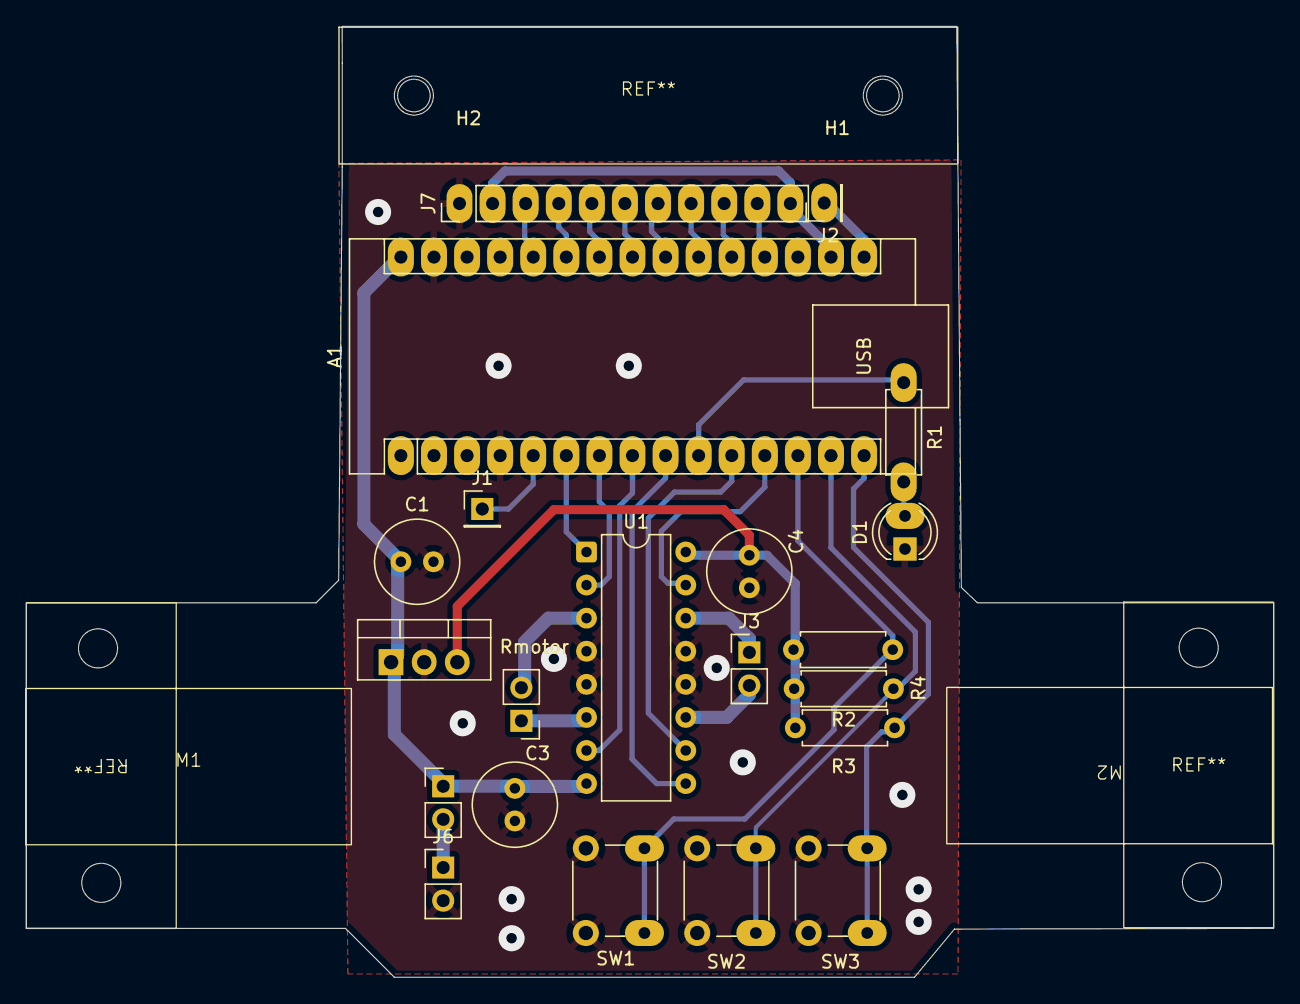
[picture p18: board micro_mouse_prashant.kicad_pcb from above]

Board: 2 copper layers, 95.8 x 73.0 mm, 25 parts (0 on the bottom side), 30 nets.

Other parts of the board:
Rmotor: Motor Right; PinHeader_1x02_P2.54mm_Vertical

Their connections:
/MR1: Rmotor.2; also elsewhere on the board
/MR2: Rmotor.1; also elsewhere on the board

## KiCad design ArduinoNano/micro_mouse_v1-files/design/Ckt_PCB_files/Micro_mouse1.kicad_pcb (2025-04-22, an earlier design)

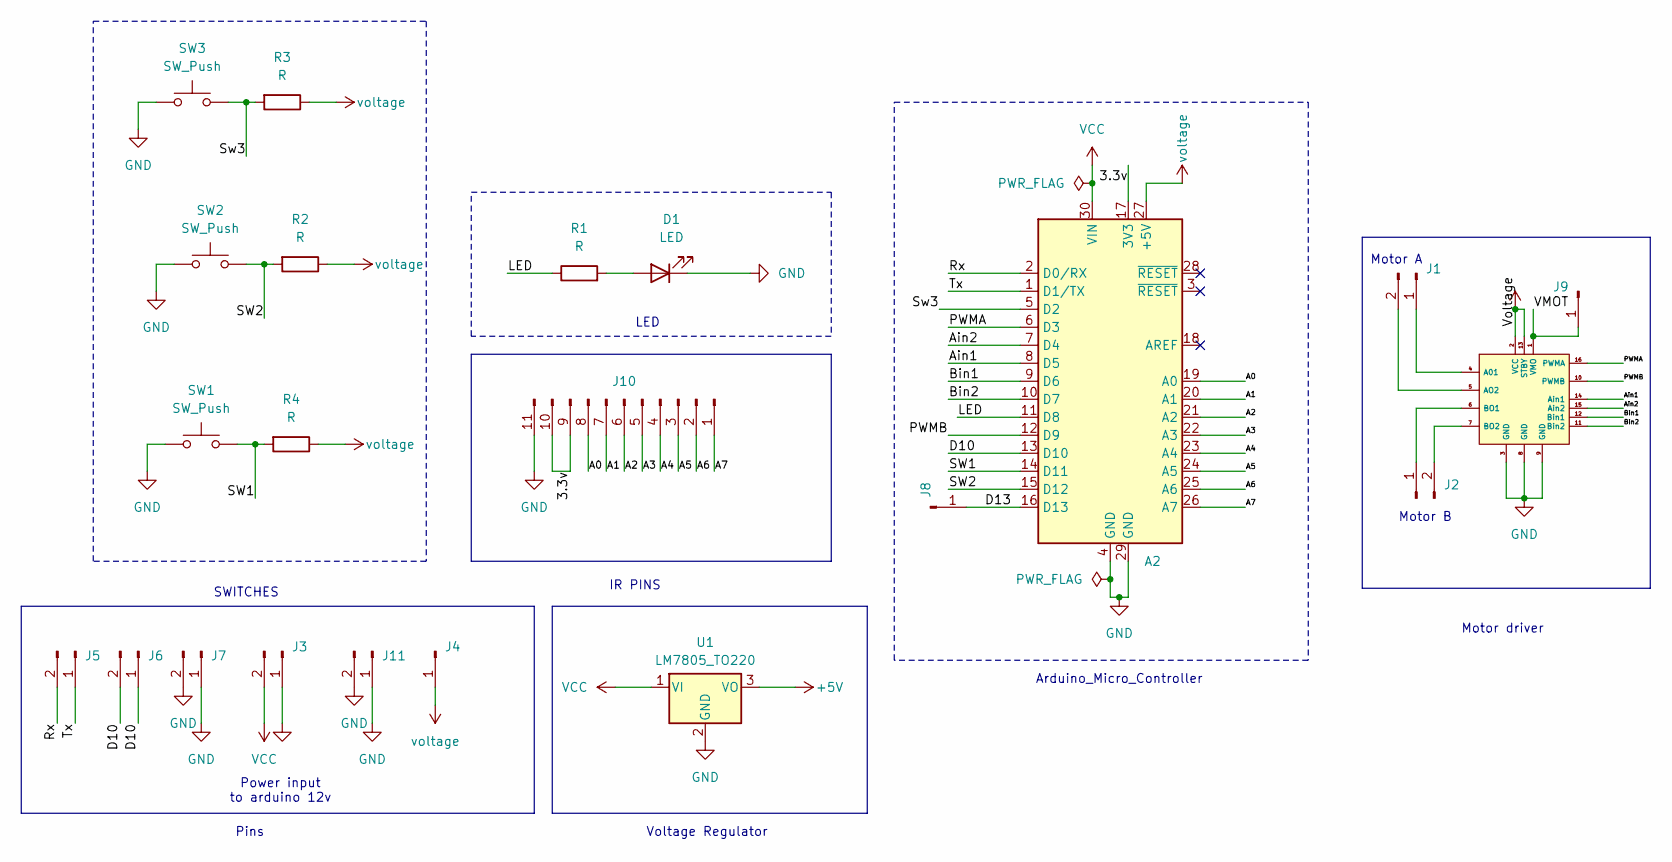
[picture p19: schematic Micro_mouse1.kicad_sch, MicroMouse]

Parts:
A2: Arduino_Nano_v3.x; Arduino_Nano
D1: LED; LED_D1.8mm_W1.8mm_H2.4mm_Horizontal_O1.27mm_Z1.6mm
J1, J2, J3, J5, J6, J7, J11: Conn_01x02_Pin; PinSocket_1x02_P2.54mm_Vertical
J4, J8, J9: Conn_01x01_Pin; PinSocket_1x01_P2.54mm_Vertical
J10: Conn_01x11_Pin; PinSocket_1x11_P2.54mm_Vertical
MD1: tbfng motor driver
R1, R2, R3, R4: R; R_Axial_DIN0204_L3.6mm_D1.6mm_P5.08mm_Horizontal
SW1, SW2, SW3: SW_Push; SW_PUSH_6mm
U1: LM7805_TO220; TO-220-3_Vertical

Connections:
+5V: MD1.2 (VCC), MD1.13 (STBY), U1.3 (VO)
/3.3v: A2.17 (3V3), J10.9, J10.10
/A0: A2.19 (A0), J10.8
/A1: A2.20 (A1), J10.7
/A2: A2.21 (A2), J10.6
/A3: A2.22 (A3), J10.5
/A4: A2.23 (A4), J10.4
/A5: A2.24 (A5), J10.3
/A6: A2.25 (A6), J10.2
/A7: A2.26 (A7), J10.1
/Ain1: A2.8 (D5), MD1.14 (Ain1)
/Ain2: A2.7 (D4), MD1.15 (Ain2)
/Bin1: A2.9 (D6), MD1.12 (Bin1)
/Bin2: A2.10 (D7), MD1.11 (Bin2)
/D10: A2.13 (D10), J6.1, J6.2
/D13: A2.16 (D13), J8.1
/LED: A2.11 (D8), R1.1
/PWMA: A2.6 (D3), MD1.16 (PWMA)
/PWMB: A2.12 (D9), MD1.10 (PWMB)
/Rx: A2.2 (D0/RX), J5.2
/SW1: A2.14 (D11), R4.2, SW1.2
/SW2: A2.15 (D12), R2.2, SW2.2
/Sw3: A2.5 (D2), R3.2, SW3.2
/Tx: A2.1 (D1/TX), J5.1
/VMOT: J9.1, MD1.1 (VMO)
GND: A2.4 (GND), A2.29 (GND), D1.1 (K), J3.1, J7.1, J7.2, J10.11, J11.1, J11.2, MD1.3 (GND), MD1.8 (GND), MD1.9 (GND), SW1.1, SW2.1, SW3.1, U1.2 (GND)
unnamed: D1.2 (A), R1.2
unnamed: J1.1, MD1.4 (A01)
unnamed: J1.2, MD1.5 (AO2)
unnamed: J2.1, MD1.6 (BO1)
unnamed: J2.2, MD1.7 (BO2)
VCC: A2.30 (VIN), J3.2, U1.1 (VI)
voltage: A2.27 (+5V), J4.1, R2.1, R3.1, R4.1

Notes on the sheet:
Motor A
Arduino_Micro_Controller
Motor driver
Voltage Regulator
Power input to arduino 12v
SWITCHES
Pins
LED
Motor B
IR PINS

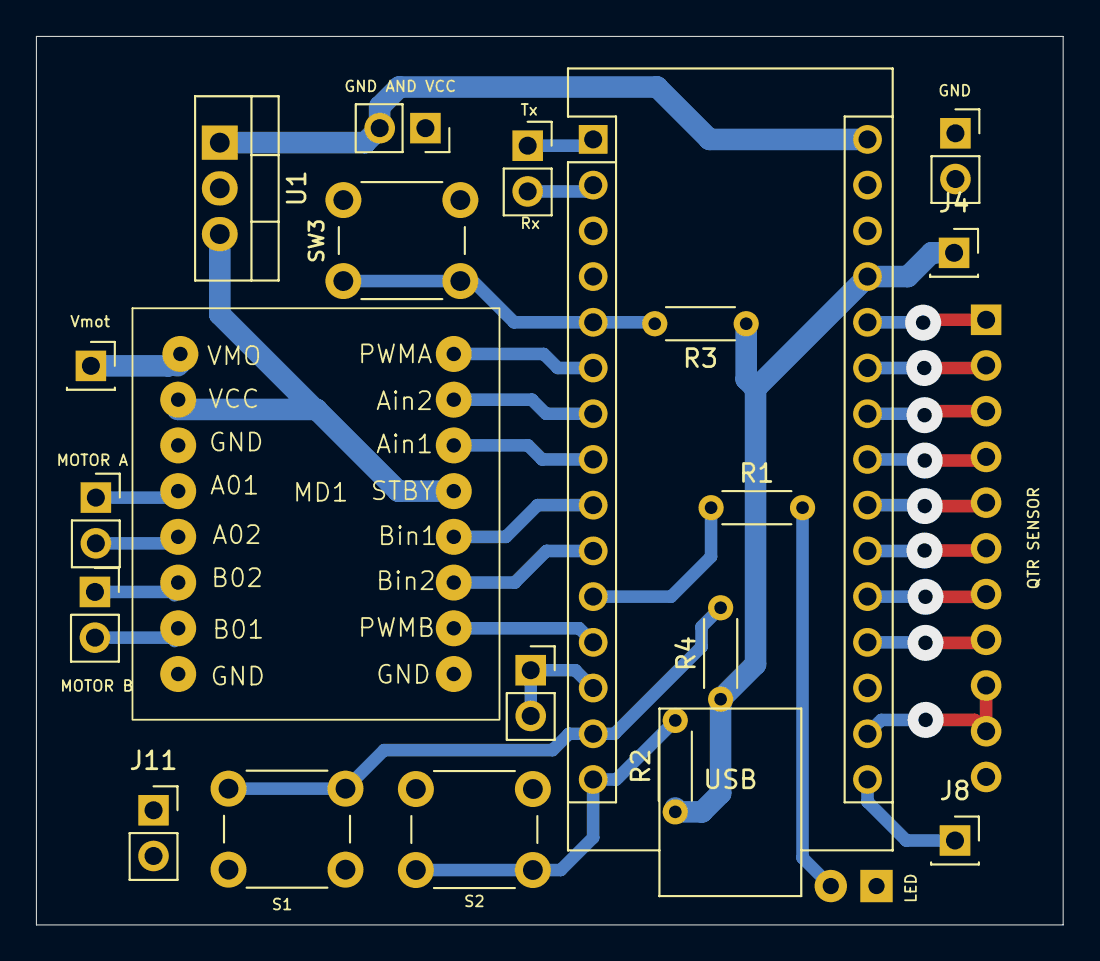
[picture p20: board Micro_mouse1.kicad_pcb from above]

Board: 2 copper layers, 57.0 x 49.4 mm, 22 parts (1 on the bottom side), 33 nets.

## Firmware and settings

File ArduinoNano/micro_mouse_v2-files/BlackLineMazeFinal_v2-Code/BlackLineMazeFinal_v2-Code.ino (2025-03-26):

// this is a code for black line in white surface



#include <SparkFun_TB6612.h>  // This libaray is for sparkfun motor driver  
#include <QTRSensors.h>       // It is for qtr sensors 

// Initialization of the motors
#define AIN1 5 //4
#define BIN1 8 //8
#define AIN2 4 //5
#define BIN2 9 //9

#define PWMA 3
#define PWMB 6

// Initialization of the controls
#define sw1 10
#define sw2 11
#define sw3 12 
#define led 7
int s1,s3,s2;
char dir;
int chr = 1;

// Initialization of sensors
#define NUM_SENSORS 8
unsigned int sensors1[8];
int thr[8];

// Initialization of PID parameter
#define MaxSpeed 255 //170
#define BaseSpeed 255 //170
int lastError = 0;
float kp = 0.151;    // It fully depends on the bot system
float kd = 0.8;    // Please follow the method provided in instructables to get your values
int last_pos = 3500;

// shortheschalneyyyt path parameters
int num = 0;
char path[100];
int path_length = 0;


// Creating the instance of class for motor and senors
Motor motor1 = Motor(AIN1, AIN2, PWMA, 1, 1); 
Motor motor2 = Motor(BIN1, BIN2, PWMB, 1, 1); // right
QTRSensors qtra;

void setup()
{
  qtra.setTypeAnalog();
  qtra.setSensorPins((const uint8_t[]) {   // QTR8A sensor setup
    A7, A6, A5, A4, A3, A2, A1, A0
  }, NUM_SENSORS);
  pinMode(sw1, INPUT);
  pinMode(sw2, INPUT);
  pinMode(sw3, INPUT);
  pinMode(led, OUTPUT);     // Control pin setup
  Serial.begin(9600);
  // while (!Serial)
  // {
  //   ;                           //Serial communication setup for bluetooth
  // }
  s1 = digitalRead(sw1);
  while (s1 == HIGH)
  {
    s1 = digitalRead(sw1);      // Calibration phase where the bot get calibrated after pressing s1 switch
  }
  digitalWrite(led,HIGH);
  delay(800);
  calibration();
  while (1)
  {
    int s2 = digitalRead(sw2);
    int s3 = digitalRead(sw3);
    if (s2 == LOW)
    {
      chr = 1;
      break;                        // Here we have to choose the Rule which will follow by the bot
                                    // S1 switch for LHS and s2 switch for RHS
                                    // In LHS left, straight, right will be priority
    }                               // In RHS right, straight, left will be priority
    if (s3 == LOW)                  
    {
      chr = 2;   
      break;
    }
  }
  Serial.println(chr);
  delay(900);
  s1 = digitalRead(sw1);
  while (s1 == HIGH)
  {
    s1 = digitalRead(sw1);      // Press s2 switch to start a bot to follow the path
  }
  delay(800);
}
void loop() {
  forward(motor1, motor2, 40);
  delay(40);
  forward(motor1, motor2, 60);
  delay(40);                              // For graduly increasing speed so that bot dose not get direct high speed at the start
  forward(motor1, motor2, 80);
  delay(40);
  maze();
}
void calibration()
{
  for (int i = 0; i <= 100; i++)
  {

    if (i < 25 || i >= 75)
    {
      left(motor1, motor2, 200); //Left turn
    }
    else
    {

      right(motor1, motor2, 200); //Right turn
    }
    qtra.calibrate();
    delay(10);
  }  // end calibration cycle
  brake(motor1, motor2);
  for (int i = 0; i < NUM_SENSORS; i++)
  {
    Serial.print(qtra.calibrationOn.minimum[i]);
    Serial.print(' ');
    thr[i] = (qtra.calibrationOn.minimum[i] + qtra.calibrationOn.maximum[i]) / 2;
    // Calculating the threshold value for making the decision above thr black line and below white line
  }
  Serial.println();
  for (int i = 0; i < NUM_SENSORS; i++)
  {
    Serial.print(qtra.calibrationOn.maximum[i]);
    Serial.print(' ');
  }
  Serial.println();
  Serial.println(thr[0]);
  Serial.println(thr[7]);
}
void follow_segment()
{
  while (1)
  {
    digitalWrite(led, LOW);
    // FOR BLACK LINE FOLLOWER JUST REPLACE White WITH Black
    int position = qtra.readLineBlack(sensors1);   // Getting the present position of the bot
    int error =  3500 - position;
    int motorSpeed = kp * error + kd * (error - lastError);
    lastError = error;
    int rightMotorSpeed = BaseSpeed - motorSpeed;
    int leftMotorSpeed = BaseSpeed + motorSpeed;
    if (rightMotorSpeed > MaxSpeed ) rightMotorSpeed = MaxSpeed;
    if (leftMotorSpeed > MaxSpeed ) leftMotorSpeed = MaxSpeed;
    if (rightMotorSpeed < 0)rightMotorSpeed = 0;
    if (leftMotorSpeed < 0)leftMotorSpeed = 0;
    motor1.drive(rightMotorSpeed);
    motor2.drive(leftMotorSpeed);
    if ((sensors1[0] > thr[0]) || (sensors1[7] > thr[7]))
    {
      return ;
      // Found an intersection.
    }
    else if (sensors1[1] < thr[1] && sensors1[2] < thr[2] && sensors1[3] < thr[3] && sensors1[4] < thr[4] && sensors1[5] < thr[5] && sensors1[6] < thr[6])
    {
      // There is no line visible ahead, and we didn't see any
      // intersection. Must be a dead end.
      return ;
    }
    delay(5);
  }
}
void maze()
{
  while (1)
  {
    // First main loop body were a goal is to store all the dead end or we say dry run path
    //After reaching at end we use break to get out of this
    follow_segment(); // It will follow the path until it dosn't get any intersection
    // brake(motor1, motor2);
    // back(motor1,motor2,100);
    // delay(1000);
    // brake(motor1,motor2);
    // delay(200);
    digitalWrite(led, HIGH);
    brake(motor1, motor2);           // After getting intersetion fist thing that we have to do
                                     // Drive straight a bit. This helps us in case we entered the
                                     // intersection at an angle
    forward(motor1, motor2, 20); //40
    delay(10); //30
    brake(motor1, motor2);
    // These variables record whether the robot has seen a line to the
    // straight ahead, and right, whil examining the current
    // intersection.
    unsigned char found_left = 0;
    unsigned char found_straight = 0;
    unsigned char found_right = 0;
    // Now read the sensors and check the intersection type.
    qtra.readLineBlack(sensors1);
    // if (sensors1[7] < thr[7])
    // {
    //   found_left = 1;
    //   if (sensors1[1] < thr[1])
    //   {
    //     found_right = 1;
    //   }
    // }
    // if (sensors1[0] < thr[0])
    // {
    //   found_right = 1;
    //   if (sensors1[6] < thr[6])
    //   {
    //     found_left = 1;

    //   }
    // }
    if(sensors1[0] > thr[0]){
    found_left = 1;
    }
    if(sensors1[7] > thr[7]){

    found_right = 1;
    }
    // Drive straight a bit more - this is enough to line up our
    //wheels with the intersection.
    forward(motor1, motor2, 20);
    delay(30); //60 //100 // 40 
    brake(motor1, motor2);
    delay(60); //60
    qtra.readLineBlack(sensors1);
    if (sensors1[1] > thr[1] || sensors1[2] > thr[2] || sensors1[3] > thr[3] || sensors1[4] > thr[4] || sensors1[5] > thr[5] || sensors1[6] > thr[6] )
    {
      found_straight = 1;
    }
    // Check for the ending spot.
    if (sensors1[1] > thr[1] && sensors1[2] > thr[2] && sensors1[3] > thr[3] && sensors1[4] > thr[4] && sensors1[5] > thr[5] && sensors1[6] > thr[6])
      break;
    // According to rule we have to decided which turn has to be taken
    if (chr == 1)
      dir = select_turnL(found_left, found_straight, found_right);
    else if (chr == 2)
      dir = select_turnR(found_right, found_straight, found_left);
    // Serial.println(dir);
    // Take a turn according to that
    turn(dir);

    // Store the intersection in the path variable.
    path[path_length] = dir;
    path_length++;
    // Simplify the path for the final run
    simplify_path();
  }
  // Now the second half is the short run which is obtained after sorting the dry run
  brake(motor1, motor2);
  forward(motor1, motor2, 50);
  delay(100);                   // Move straight a bit on end point and glow a led
  brake(motor1, motor2);
  for (int w = 0; w < path_length; w++)
  {
    Serial.print(path[w]);
    Serial.print(' ');
  }
  digitalWrite(led, HIGH);
  delay(4000);
  digitalWrite(led, LOW);
  s2 = digitalRead(sw2);
  while (s2 == HIGH)
  {
    s2 = digitalRead(sw2);     // Wait for pressing a switch
  }
  delay(800);
  forward(motor1, motor2, 30);
  delay(40);
  forward(motor1, motor2, 50);
  delay(40);
  forward(motor1, motor2, 70);
  delay(40);
  while (1) //path
  {
    int k;
    for (k = 0; k < path_length; k++)
    {
      follow_segment();
      forward(motor1, motor2, 60); //60    // After reaching a intercetion follow the shortest path turn
      delay(60); 
      // forward(motor1, motor2, 60);
      // delay(100);
      brake(motor1, motor2);
      delay(5);
      turn(path[k]);
    }
    follow_segment();
    brake(motor1, motor2);
    forward(motor1, motor2, 80);
    delay(400);
    brake(motor1, motor2);
    digitalWrite(led, HIGH);
    delay(4000);
    digitalWrite(led, LOW);


  // s2 = digitalRead(sw2);
  // while (s2 == HIGH)
  // {
  //   s2 = digitalRead(sw2);     // Wait for pressing a switch
  // }
  while (1)
  {
    // First main loop body were a goal is to store all the dead end or we say dry run path
    //After reaching at end we use break to get out of this
    follow_segment(); // It will follow the path until it dosn't get any intersection
    // brake(motor1, motor2);
    // back(motor1,motor2,100);
    // delay(1000);
    // brake(motor1,motor2);
    // delay(200);
    digitalWrite(led, HIGH);
    brake(motor1, motor2);           // After getting intersetion fist thing that we have to do
                                     // Drive straight a bit. This helps us in case we entered the
                                     // intersection at an angle
    forward(motor1, motor2, 20); //40
    delay(10); //30
    brake(motor1, motor2);
    // These variables record whether the robot has seen a line to the
    // straight ahead, and right, whil examining the current
    // intersection.
    unsigned char found_left = 0;
    unsigned char found_straight = 0;
    unsigned char found_right = 0;
    // Now read the sensors and check the intersection type.
    qtra.readLineBlack(sensors1);
    // if (sensors1[7] < thr[7])
    // {
    //   found_left = 1;
    //   if (sensors1[1] < thr[1])
    //   {
    //     found_right = 1;
    //   }
    // }
    // if (sensors1[0] < thr[0])
    // {
    //   found_right = 1;
    //   if (sensors1[6] < thr[6])
    //   {
    //     found_left = 1;

    //   }
    // }
    if(sensors1[0] > thr[0]){
    found_left = 1;
    }
    if(sensors1[7] > thr[7]){

    found_right = 1;
    }
    // Drive straight a bit more - this is enough to line up our
    //wheels with the intersection.
    forward(motor1, motor2, 20);
    delay(30); //60 //100 // 40 
    brake(motor1, motor2);
    delay(60); //60
    qtra.readLineBlack(sensors1);
    if (sensors1[1] > thr[1] || sensors1[2] > thr[2] || sensors1[3] > thr[3] || sensors1[4] > thr[4] || sensors1[5] > thr[5] || sensors1[6] > thr[6] )
    {
      found_straight = 1;
    }
    // Check for the ending spot.
    if (sensors1[1] > thr[1] && sensors1[2] > thr[2] && sensors1[3] > thr[3] && sensors1[4] > thr[4] && sensors1[5] > thr[5] && sensors1[6] > thr[6])
      break;
    // According to rule we have to decided which turn has to be taken
    if (chr == 1)
      dir = select_turnL(found_left, found_straight, found_right);
    else if (chr == 2)
      dir = select_turnR(found_right, found_straight, found_left);
    // Serial.println(dir);
    // Take a turn according to that
    turn(dir);

    // Store the intersection in the path variable.
    path[path_length] = dir;
    path_length++;
    // Simplify the path for the final run
    simplify_path();
  }

  }
  // Go back to a starting of the main loop
}
char select_turnL(char found_left, char found_straight, char found_right)
{
  // Make a decision about how to turn. The following code
  // Implements a left-hand-on-the-wall strategy, where we always preffer left turn
  if (found_left)
    return 'L';
  else if (found_straight)
    return 'S';
  else if (found_right)
    return 'R';
  else
    return 'B';
}
char select_turnR(char found_right, char found_straight, char found_left)
{
  // Make a decision about how to turn. The following code
  // Implements a right-hand-on-the-wall strategy, Where we always preffer right turn
  if (found_right)
    return 'R';
  else if (found_straight)
    return 'S';
  else if (found_left)
    return 'L';
  else
    return 'B';
}
void turn(char dir)
{
  int line_position;
  // According to dir perform a turn
  switch (dir)
  {
    case'L':
      left(motor1, motor2, 300);
      qtra.readLineBlack(sensors1);
      while (sensors1[0] < thr[0])
      {
        line_position = qtra.readLineBlack(sensors1);    //Move left until left extreme sensor goes out of the white line comes on black
      }
      qtra.readLineBlack(sensors1);
      left(motor1, motor2, 150);
      while (sensors1[0] > thr[0])
      {
        line_position = qtra.readLineBlack(sensors1);        // Again move left until it get's on white line
      }
      follow_segment1();    // Fast pid after turn to align bot quickly on line
      brake(motor1, motor2);
      break;
    case'R':
      right(motor1, motor2, 300); //250
      qtra.readLineBlack(sensors1);
      while (sensors1[7] < thr[7])
      {
        line_position = qtra.readLineBlack(sensors1);   //Move right until left extreme sensor goes out of the white line comes on black
      }
      qtra.readLineBlack(sensors1);
      right(motor1, motor2, 150); //150
      while (sensors1[7] > thr[7])
      {
        line_position = qtra.readLineBlack(sensors1);         // Again move right until it get's on white line
      }
      follow_segment1();      // Fast pid after turn to align a bot quickly on line
      brake(motor1, motor2);
      break;
    case'B':
      // right(motor1, motor2, 230);
      // qtra.readLineBlack(sensors1);
      // while (sensors1[7 ] > thr[7])
      // {
      //   line_position = qtra.readLineBlack(sensors1);          // Take u turn using right turn
      // }
      // qtra.readLineBlack(sensors1);
      // right(motor1, motor2, 150);

      // while (sensors1[7] < thr[7])
      // {
      //   line_position = qtra.readLineBlack(sensors1);
      // }
      // follow_segment3();
      // brake(motor1, motor2);
      // delay(50);
      // follow_segment2();    // Back moving pid
      // forward(motor1, motor2, 40);
      // delay(40);
      // break;
      left(motor1, motor2, 250);
      qtra.readLineBlack(sensors1);
      while (sensors1[0] < thr[0])
      {
        line_position = qtra.readLineBlack(sensors1);    //Move left until left extreme sensor goes out of the white line comes on black
      }
      qtra.readLineBlack(sensors1);
      left(motor1, motor2, 150);
      while (sensors1[0] > thr[0])
      {
        line_position = qtra.readLineBlack(sensors1);        // Again move left until it get's on white line
      }
      follow_segment1();    // Fast pid after turn to align bot quickly on line
      brake(motor1, motor2);
      // follow_segment2();    // Back moving pid
      // forward(motor1, motor2, 40);
      // delay(40);
      break;
  }
}
void follow_segment1()
{
  // Fast pid after turn to get quickly align a bot on line
  int Kp = 0.1;
  int Kd = 10; //40
  for (int j = 0; j < 30; j++) {
    int position = qtra.readLineBlack(sensors1);       // FOR BLACK LINE FOLLOWER JUST REPLACE White WITH Black
    int error =  3500 - position;
    int motorSpeed = Kp * error + Kd * (error - lastError);
    lastError = error;
    int rightMotorSpeed = BaseSpeed - motorSpeed;
    int leftMotorSpeed = BaseSpeed + motorSpeed;
    if (rightMotorSpeed > MaxSpeed ) rightMotorSpeed = MaxSpeed;
    if (leftMotorSpeed > MaxSpeed ) leftMotorSpeed = MaxSpeed;
    if (rightMotorSpeed < 0)rightMotorSpeed = 0;
    if (leftMotorSpeed < 0)leftMotorSpeed = 0;
    motor1.drive(rightMotorSpeed);
    motor2.drive(leftMotorSpeed);
    delay(1);
  }
}
void simplify_path()
{
  // Path simplification. The strategy is that whenever we encounter a
  // sequence xBx, we can simplify it by cutting out the dead end.

  if (path_length < 3 || path[path_length - 2] != 'B')      // simplify the path only if the second-to-last turn was a 'B'
    return;
  int total_angle = 0;
  int m;
  // Get the angle as a number between 0 and 360 degrees.
  for (m = 1; m <= 3; m++)
  {
    switch (path[path_length - m])
    {
      case 'R':
        total_angle += 90;
        break;
      case 'L':
        total_angle += 270;
        break;
      case 'B':
        total_angle += 180;
        break;
    }
  }
  // Replace all of those turns with a single one.
  total_angle = total_angle % 360;
  switch (total_angle)
  {
    case 0:
      path[path_length - 3] = 'S';
      break;
    case 90:
      path[path_length - 3] = 'R';
      break;
    case 180:
      path[path_length - 3] = 'B';
      break;
    case 270:
      path[path_length - 3] = 'L';
      break;
  }
  path_length -= 2;
}
void follow_segment2()
{
  //Back moving pid
  int Kp = 1;
  int Kd = 200; //80
  int baseSpeed = 100;
  int maxSpeed = 100;
  for (int j = 0; j < 100; j++) {
    int position = qtra.readLineBlack(sensors1);       // FOR BLACK LINE FOLLOWER JUST REPLACE White WITH Black
    int error =  3500 - position;
    int motorSpeed = Kp * error + Kd * (error - lastError);
    lastError = error;
    int rightMotorSpeed = baseSpeed + motorSpeed;
    int leftMotorSpeed = baseSpeed - motorSpeed;
    if (rightMotorSpeed > maxSpeed ) rightMotorSpeed = maxSpeed;
    if (leftMotorSpeed > maxSpeed ) leftMotorSpeed = maxSpeed;
    if (rightMotorSpeed < 0)rightMotorSpeed = 0;
    if (leftMotorSpeed < 0)leftMotorSpeed = 0;
    motor1.drive(-rightMotorSpeed);
    motor2.drive(-leftMotorSpeed);
    delay(1);
  }
}
void follow_segment3()
{
  int Kp = 1;
  int Kd =50; //20
  for (int j = 0; j < 10; j++) {
    int position = qtra.readLineBlack(sensors1);       // FOR BLACK LINE FOLLOWER JUST REPLACE White WITH Black
    int error = 3500 - position;
    int motorSpeed = Kp * error + Kd * (error - lastError);
    lastError = error;
    int rightMotorSpeed = BaseSpeed - motorSpeed;
    int leftMotorSpeed = BaseSpeed + motorSpeed;
    if (rightMotorSpeed > MaxSpeed ) rightMotorSpeed = MaxSpeed;
    if (leftMotorSpeed > MaxSpeed ) leftMotorSpeed = MaxSpeed;
    if (rightMotorSpeed < 0)rightMotorSpeed = 0;
    if (leftMotorSpeed < 0)leftMotorSpeed = 0;
    motor1.drive(rightMotorSpeed);
    motor2.drive(leftMotorSpeed);
    delay(1);
  }
}

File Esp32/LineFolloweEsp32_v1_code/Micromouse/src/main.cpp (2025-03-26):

// Download below two library on your arduino IDE you will get this from google
#include <SparkFun_TB6612.h>  // This libaray is for sparkfun motor driver  
#include <QTRSensors.h>       // It is for qtr sensors 

// Initialization of the motors
#define AIN1 18
#define BIN1 16
#define AIN2 5
#define BIN2 17
#define PWMA 19
#define PWMB 4



const int offsetA = 1;
const int offsetB = 1;

// Initialization of the controls
#define sw1 26
#define sw2 27
#define led 23
int s1;




// Initialization of sensors
#define NUM_SENSORS 8
uint16_t sensors1[8];
int thr[8];

// Initialization of PID parameter
#define MaxSpeed 130
#define BaseSpeed 130
int lastError = 0;
float kp = 0.05;    // It fully depends on the bot system
float kd = 0.1;    // Please follow the method provided in instructables to get your values
int last_pos = 3500;




// Creating the instance of class for motor and senors
Motor motor2 = Motor(BIN1, BIN2, PWMB, 1, 1);
Motor motor1 = Motor(AIN1, AIN2, PWMA, 1, 1); //right

QTRSensors qtra;



void calibration()
{

  for (int i = 0; i <= 100; i++)
  {

    if (i < 25 || i >= 75)
    {
      left(motor1, motor2, 180); //Left turn

    }
    else
    {

      right(motor1, motor2, 180); //Right turn
    }

    qtra.calibrate();
    delay(10);
  }  // end calibration cycle
  brake(motor1, motor2);
  for (int i = 0; i < NUM_SENSORS; i++)
  {
    Serial.print(qtra.calibrationOn.minimum[i]);
    Serial.print(' ');
    thr[i] = (qtra.calibrationOn.minimum[i] + qtra.calibrationOn.maximum[i]) / 2;
    // Calculating the threshold value for making the decision above thr black line and below white line
  }

  Serial.println();
  for (int i = 0; i < NUM_SENSORS; i++)
  {
    Serial.print(qtra.calibrationOn.maximum[i]);
    Serial.print(' ');
  }
  Serial.println();
  Serial.println(thr[0]);
  Serial.println(thr[7]);


 }

void follow_segment1()
{
    while(1){
    int position = qtra.readLineWhite(sensors1);       // FOR BLACK LINE FOLLOWER JUST REPLACE White WITH Black
    int error =  3500 - position;

    // Serial.println("position");
    // Serial.println(position);
    int motorSpeed = kp * error + kd * (error - lastError);
    lastError = error;
    int rightMotorSpeed = BaseSpeed - motorSpeed;
    int leftMotorSpeed = BaseSpeed + motorSpeed;
    if (rightMotorSpeed > MaxSpeed ) rightMotorSpeed = MaxSpeed;
    if (leftMotorSpeed > MaxSpeed ) leftMotorSpeed = MaxSpeed;
    if (rightMotorSpeed < 0)rightMotorSpeed = 0;
    if (leftMotorSpeed < 0)leftMotorSpeed = 0;

    // Serial.print("Right Motor Speed: ");
    // Serial.println(rightMotorSpeed);
    // Serial.print("Left Motor Speed: ");
    // Serial.println(leftMotorSpeed);

    
    motor1.drive(leftMotorSpeed);
    motor2.drive(rightMotorSpeed);


    delay(1);
    }
  }



void setup()
{
  qtra.setTypeAnalog();
  qtra.setSensorPins((const uint8_t[]) {   // QTR8 sensor setup
    15,25,33,32,35,34,39,36
  }, NUM_SENSORS);

  pinMode(sw1, INPUT);
  pinMode(sw2, INPUT);


  Serial.begin(115200);
 

  s1 = digitalRead(sw1);
  while (s1 == HIGH)
  {
    s1 = digitalRead(sw1);      // Calibration phase where the bot get calibrated after pressing s1 switch
  }
  delay(800);
  calibration();
  
}
void loop() {
  s1 = digitalRead(sw1);
  while (s1 == HIGH)
  {
    s1 = digitalRead(sw1);      //s1 to start following line
  }
  delay(800);
  // forward(motor1, motor2, 60);
  // delay(40);
  // forward(motor1, motor2, 80);
  // delay(40);                              // For graduly increasing speed so that bot does not get direct high speed at the start
  // forward(motor1, motor2, 100);
  // delay(40);
  follow_segment1();
}

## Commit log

2025-03-26 Upladed all the files of micromouse
    [Micro_mouse1.kicad_pcb, Micro_mouse1.kicad_sch, micromouse3.0.kicad_pcb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]
2025-09-25 Updated files of the Micro Mouse with V3, and Esp on pending
    [DOBLE PUENTE H.step, Micro_mouse1.kicad_pcb, Micro_mouse1.kicad_sch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]

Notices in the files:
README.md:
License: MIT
